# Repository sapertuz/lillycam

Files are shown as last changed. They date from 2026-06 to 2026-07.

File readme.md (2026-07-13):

# LillyCam 🐱

A DIY cat treat dispenser with live camera, two-way audio, and remote control —
built on a Raspberry Pi Zero W (or a Zero 2 W for the "Pro" build).

<p align="center">
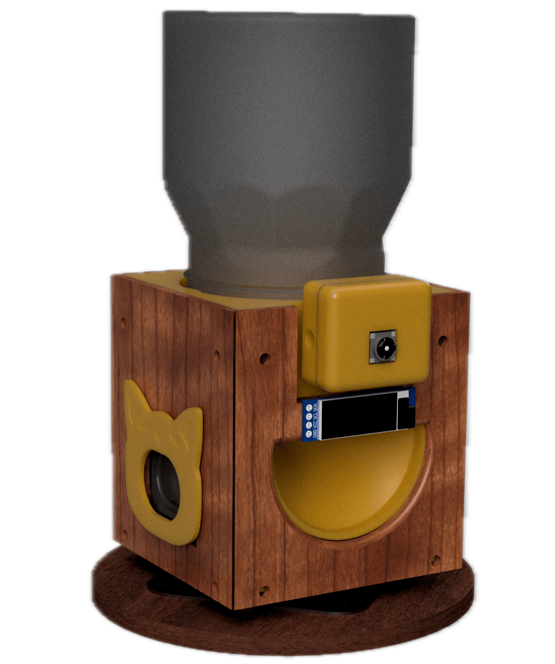
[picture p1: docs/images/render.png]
LillyCam enclosure render
  
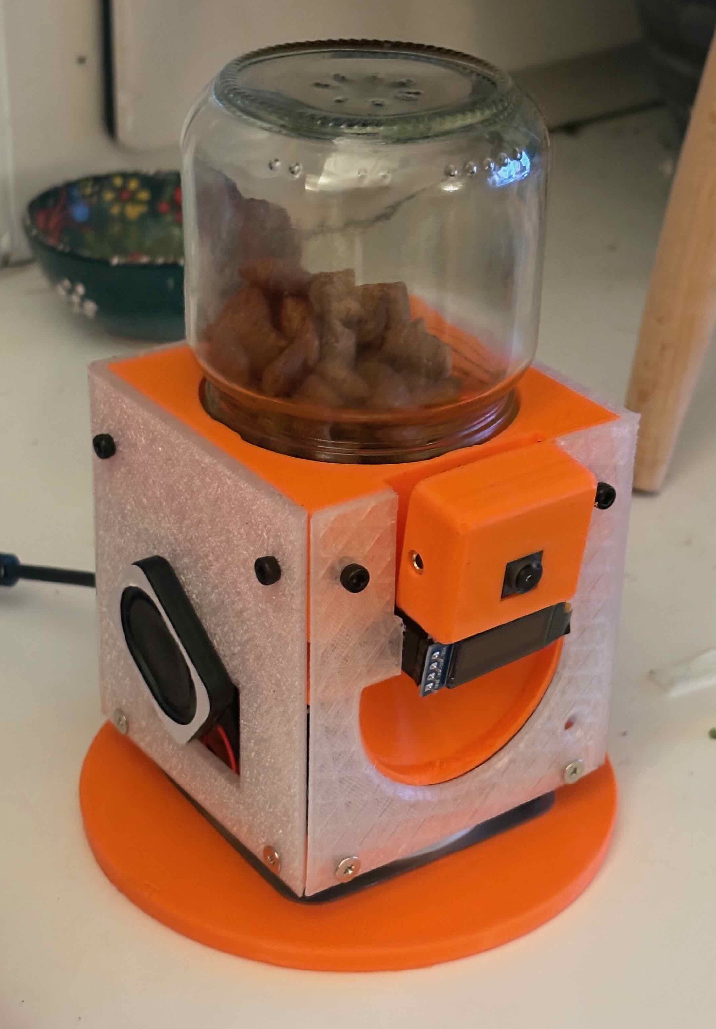
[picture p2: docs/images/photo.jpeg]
LillyCam assembled and running
  
</p>

LillyCam remixes the classic cereal-dispenser-as-pet-feeder concept with a proper
monitoring stack: MJPEG video streaming, walkie-talkie audio, servo-controlled
rotation, OLED status display, and a web interface you can access from anywhere
via Tailscale VPN.

Everything is cat-themed. The speaker grille is a Popcat. The camera has a cat-eye
surround. The mic has a paw print. The corner pieces are fish.

## Features

- **Live video** — 640x480 @ 15fps MJPEG stream via Flask, up to 1280x720 @ 30fps on Pro (off by default at boot; wake it from the web UI)
- **Treat dispensing** — 28BYJ-48 5V stepper motor with a cylindrical funnel insert
- **Base rotation** — SG90 servo for panning the whole unit
- **Two-way audio** — INMP441 I2S mic + MAX98357A amp (half-duplex, push-to-talk)
- **Status display** — SSD1306 OLED with an animated cat face (sleeps when the camera is off, wakes when on) plus connection status and last dispense time
- **Single-connection control** — only one device drives LillyCam at a time (saves resources, avoids servo/dispenser conflicts); a second device sees a lock screen and can take over. The camera turns off automatically when the last viewer leaves
- **Full-res stills** — 3280x2464 captures saved with timestamps
- **Remote access** — Tailscale VPN, accessible from phone or laptop
- **3D printed enclosure** — cat-themed decorative panels (editable STEP + print-ready STL in [`3d-models/`](3d-models/))

<p align="center">
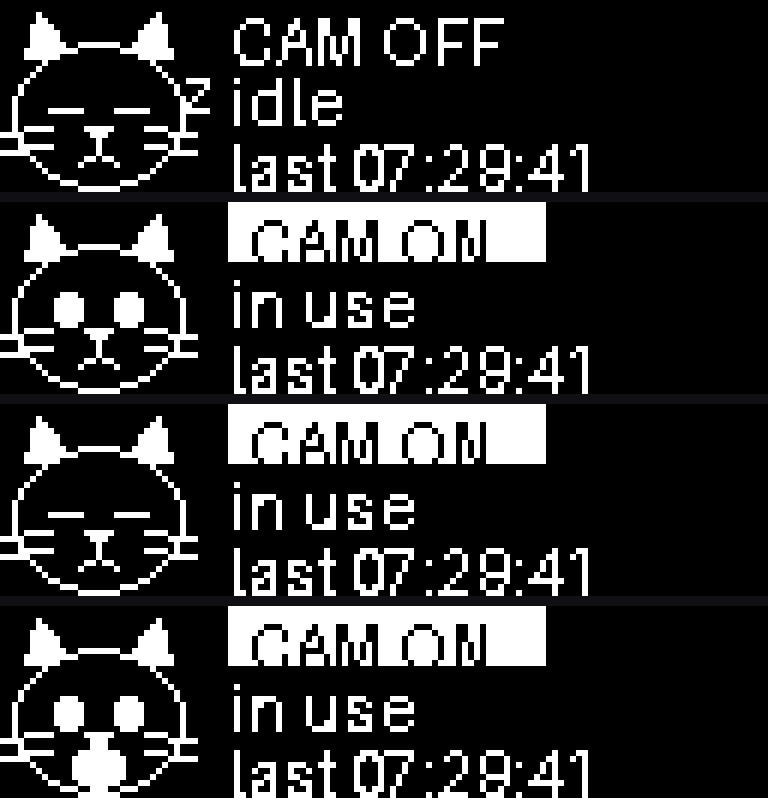
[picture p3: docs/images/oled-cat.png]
OLED cat face states: sleeping when the camera is off, awake when on, blinking, and popping on dispense
  
  <br><em>The OLED cat: sleeps when the camera is off, wakes when on, and pops on dispense.</em>
</p>

## Two models

Set `LILLYCAM_MODEL` in `.env` to `standard` or `pro` (it sets per-model defaults;
any setting can still be overridden):

| | **LillyCam** (`standard`) | **LillyCam Pro** (`pro`) |
|---|---|---|
| Computer | Pi Zero W v1.1 | Pi Zero 2 W |
| Camera | Camera Module v2 (IMX219) | Camera Module 3 (IMX708) |
| Stream default | 640x480 @ 15fps | 1280x720 @ 30fps |
| OLED animation | 6 fps | 12 fps |

## Hardware

| Component | Model | Interface |
|---|---|---|
| Computer | Raspberry Pi Zero W v1.1 | — |
| Camera | Pi Camera v2 (IMX219) | CSI ribbon |
| Stepper motor | 28BYJ-48 5V | ULN2003 driver |
| Servo | SG90 | GPIO 12 (HW PWM1) |
| Microphone | INMP441 | I2S |
| Amplifier | MAX98357A | I2S |
| Speaker | 25x35mm 4ohm 3W | via MAX98357A |
| Display | SSD1306 0.91" OLED | I2C |

Full BOM with sourcing links: [docs/hardware.md](docs/hardware.md)

## GPIO Pinout

All pin assignments live in [`lillycam/pins.py`](lillycam/pins.py).
The diagram below shows the complete 40-pin header allocation:

Pi Zero W pin header allocation for LillyCam

**Subsystem summary:**

| Subsystem | GPIO pins (BCM) | Physical pins |
|---|---|---|
| Stepper (ULN2003) | 17, 27, 22, 23 | 11, 13, 15, 16 |
| Servo (SG90) | 12 (PWM1) | 32 |
| I2S bus (shared) | 18 (BCLK), 19 (LRCLK) | 12, 35 |
| Amp (MAX98357A) | 21 (DIN) | 40 |
| Mic (INMP441) | 20 (DOUT) | 38 |
| OLED (SSD1306) | 2 (SDA), 3 (SCL) | 3, 5 |

> **Why is the servo on GPIO 12 instead of GPIO 18?**
> GPIO 18 is the default for both hardware PWM0 and I2S BCLK. Since we need I2S
> for audio, the servo was moved to GPIO 12 (hardware PWM1) to avoid the conflict.

## Quick Start

### Prerequisites

- Raspberry Pi Zero W (standard) or Zero 2 W (Pro) with Raspberry Pi OS
- All hardware connected per [docs/hardware.md](docs/hardware.md)
- I2S overlays enabled per [docs/pi-setup.md](docs/pi-setup.md)
- SSH access (USB gadget Ethernet or WiFi)

### Install

```bash
sudo apt install -y python3-picamera2
git clone https://github.com/sapertuz/lillycam.git
cd lillycam
python3 -m venv --system-site-packages .venv
source .venv/bin/activate
pip install -r requirements.txt
cp .env.example .env        # then set LILLYCAM_MODEL=standard or pro
```

### Test peripherals individually

Each script in `examples/` tests one peripheral in isolation.
Run them in order to verify your wiring:

```bash
# 1. OLED (simplest, good sanity check)
python examples/test_oled.py

# 2. Stepper motor
python examples/test_stepper.py --steps 200

# 3. Servo
python examples/test_servo.py --angle 90

# 4. Camera still
python examples/test_camera.py

# 5. MJPEG stream (open http://<pi-ip>:8080 in browser)
python examples/test_stream.py

# 6. Microphone (records 5s to test.wav)
python examples/test_mic.py

# 7. Speaker (plays test tone)
python examples/test_speaker.py

# 8. Audio loopback (records then plays back)
python examples/test_audio_loopback.py
```

### Run the full application

```bash
python -m lillycam
```

Then open `http://<pi-ip>:5000` in your browser.

### Remote access (Tailscale)

LillyCam is designed for remote access over [Tailscale](https://tailscale.com), a
private VPN. See [docs/pi-setup.md](docs/pi-setup.md) for install instructions.

Once set up, access LillyCam from any device on your Tailscale network at
`https://<tailscale-hostname>:5000`. HTTPS is required for the push-to-talk
microphone feature to work (browser security restriction).

### Run as a service

```bash
sudo cp config/lillycam.service /etc/systemd/system/
sudo systemctl daemon-reload
sudo systemctl enable lillycam
sudo systemctl start lillycam
```

LillyCam will now start automatically on boot and restart on crash.

Common service commands:

```bash
sudo systemctl restart lillycam   # restart after a code change
sudo systemctl stop lillycam      # stop
sudo systemctl status lillycam    # check if running
sudo journalctl -u lillycam -f    # live logs
```

## Project Structure

```
lillycam/
├── README.md              ← you are here
├── CLAUDE.md              (project context for AI-assisted development)
├── LICENSE                (Apache 2.0)
├── NOTICE                 (attribution)
├── pyproject.toml
├── requirements.txt
├── .env.example           (pin overrides, stream settings)
├── docs/                  (hardware BOM, assembly guide, Pi setup)
├── config/                (ALSA, boot overlays, systemd unit)
├── 3d-models/             (CAD: editable STEP + print-ready STL)
│   ├── step/              (editable source, opens in any CAD tool)
│   └── stl/               (print-ready meshes)
├── examples/              (one script per peripheral, standalone tests)
├── lillycam/              (main application)
│   ├── pins.py            (single source of truth for GPIO assignments)
│   ├── camera.py          (picamera2 wrapper)
│   ├── stepper.py         (treat dispensing)
│   ├── servo.py           (base rotation)
│   ├── audio.py           (half-duplex mic + speaker)
│   ├── display.py         (OLED status)
│   ├── app.py             (Flask factory)
│   └── web/               (routes, templates, static)
└── tests/                 (unit tests with mocked GPIO)
```

## Power

A single DC barrel jack feeds a toggle switch, then a perfboard that distributes
power through polyfused (PPTC) branches:

- ~1A polyfuse: 5V to GPIO pins 2/4, powers Pi + camera + I2S devices + servo + stepper

The Pi is powered via GPIO 5V pins (bypassing the onboard micro-USB polyfuse),
which is why the external polyfuse is required.

## License

Apache License 2.0. See [LICENSE](LICENSE) and [NOTICE](NOTICE).

## Acknowledgments

- Hardware design inspired by ["Pavlov's Electronic Treat Dispenser (PET Dispenser)"](https://www.instructables.com/Pavlovs-Electronic-Treat-Dispenser-PET-Dispenser/) on Instructables
- [picamera2](https://github.com/raspberrypi/picamera2) by the Raspberry Pi Foundation
- [luma.oled](https://github.com/rm-hull/luma.oled) by Richard Hull

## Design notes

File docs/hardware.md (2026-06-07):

# Hardware Reference

## Bill of Materials

| Component | Model | Qty | Notes |
|---|---|-----|---|
| Compute | Raspberry Pi Zero W v1.1 | 1 | 32-bit, BCM2835, 512MB RAM |
| Camera | Pi Camera v2 (IMX219) | 1 | CSI ribbon connector |
| Stepper motor | 28BYJ-48 5V unipolar | 1 | 64:1 gearbox, ~240mA |
| Stepper driver | ULN2003 breakout | 1 | Included with most 28BYJ-48 kits |
| Servo | SG90 | 1 | Hardware PWM on `GPIO 12` |
| Microphone | INMP441 I2S MEMS | 1 | Bottom-port, acoustic inlet on solder-pad side |
| Amplifier | MAX98357A I2S mono amp | 1 | 3W class-D |
| Speaker | 25×35mm, 4Ω, 3W | 1 | Fits Popcat grille STL |
| Display | SSD1306 0.91" OLED | 1 | 128×32, I2C address 0x3C |
| Power supply | 5V DC, 2A+ | 1 | Barrel jack |
| Polyfuse | PPTC, 1A | 1 | On Pi+peripherals branch |
| Misc | Perfboard, ribbon cables, JST connectors | — | |

## GPIO Pin Map

See pin diagram in `readme.md` or `CLAUDE.md`.

All BCM pin numbers are defined in `lillycam/pins.py`.

## Wiring Notes

### 28BYJ-48 Stepper + ULN2003

The ULN2003 breakout has a 5-pin JST connector that mates directly with the 28BYJ-48.
Connect the 4 input pins (IN1-IN4) to `GPIO 17, 27, 22, 23` respectively.
Power the ULN2003 from the same 5V rail as the Pi (shares polyfuse branch - the 28BYJ-48
draws ~240mA, which is within the 1A budget with headroom).

### INMP441 Microphone

Wire orientation matters: the acoustic inlet (hole) is on the side with solder pads,
not the component side. Mount with the inlet facing toward the sound source.

| INMP441 pin | Pi pin |
|---|---|
| VDD | **3V3** (pin 1) |
| GND | GND |
| SD (DOUT) | GPIO 20 (physical 38) |
| WS (LRCLK) | GPIO 19 (physical 35) |
| SCK (BCLK) | GPIO 18 (physical 12) |
| L/R | **GND** (selects left I2S channel) |

**Important:**
- VDD must be **3.3V, not 5V**. The INMP441 absolute maximum is 3.6V; at 5V it will
  not function and may be damaged.
- L/R must be tied to GND (or 3.3V for right channel). If left floating, the mic
  does not know which I2S timeslot to use and outputs silence.
- GAIN (if present on your breakout) can be left unconnected.

### MAX98357A Amplifier

| MAX98357A pin | Pi pin |
|---|---|
| VIN | 5V |
| GND | GND |
| DIN | GPIO 21 (physical 40) |
| BCLK | GPIO 18 (physical 12) |
| LRC | GPIO 19 (physical 35) |
| SD (shutdown) | Leave floating (pulled high on breakout = always on) |
| GAIN | Leave floating (15 dB, maximum hardware gain) |

GAIN options for reference: GND = 3 dB, VDD = 12 dB, floating = 15 dB.
Software gain can be adjusted via `AUDIO_PLAYBACK_GAIN` in `.env`.

### SSD1306 OLED

| OLED pin | Pi pin |
|---|---|
| VCC | 3V3 |
| GND | GND |
| SDA | GPIO 2 (physical 3) |
| SCL | GPIO 3 (physical 5) |

I2C address: `0x3C` (most common; some modules use `0x3D`).

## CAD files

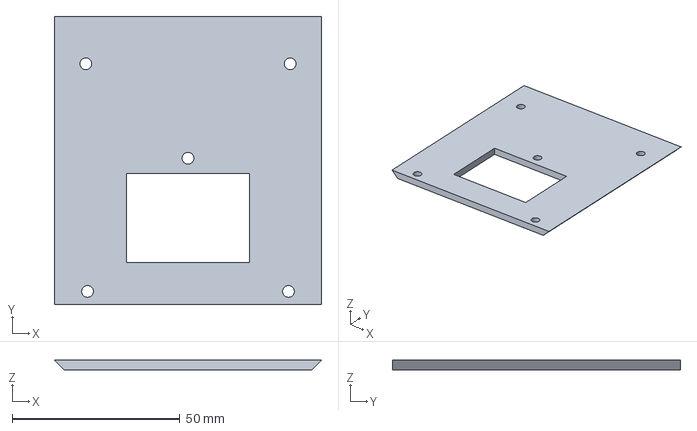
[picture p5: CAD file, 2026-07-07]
3d-models/step/enclosure_body_right.step
79.7 x 85.8 x 2.85 mm

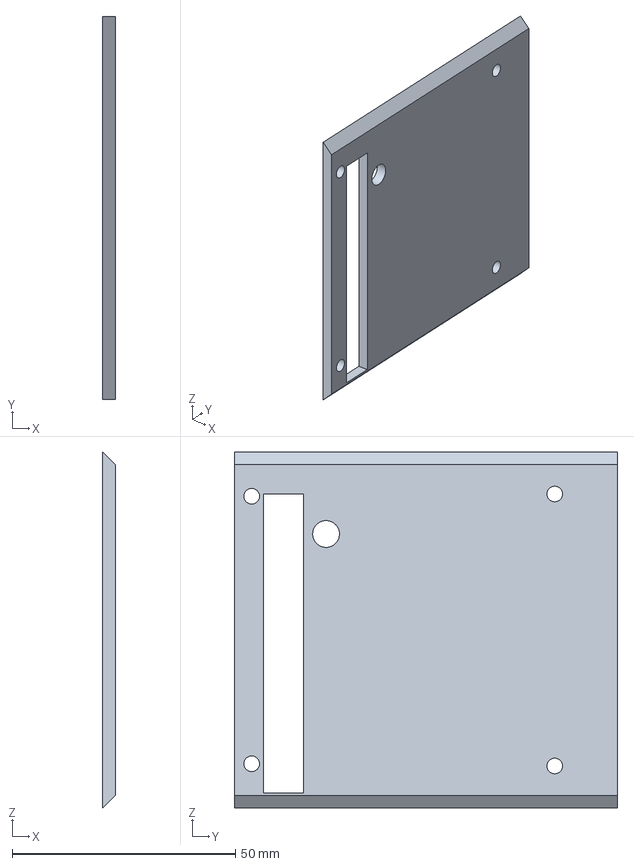
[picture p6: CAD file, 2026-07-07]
3d-models/step/enclosure_body_back.step
2.85 x 85.8 x 79.7 mm

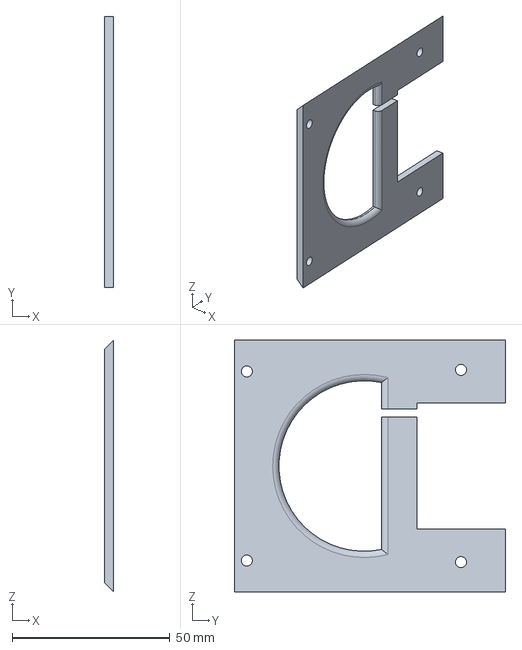
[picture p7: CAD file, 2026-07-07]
3d-models/step/enclosure_body_front.step
2.85 x 85.8 x 79.7 mm

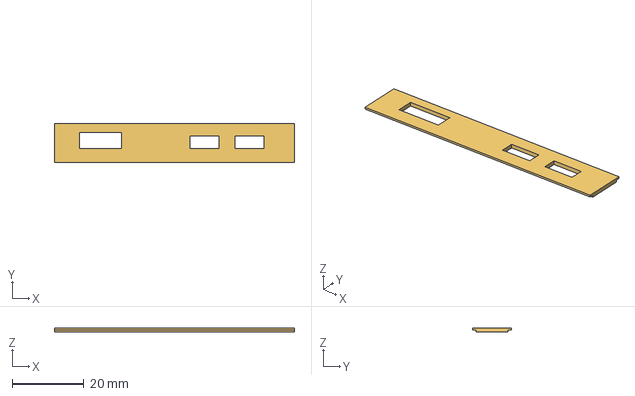
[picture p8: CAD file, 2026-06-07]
3d-models/step/pi_case_lid.step
67.0 x 11.0 x 1.00 mm

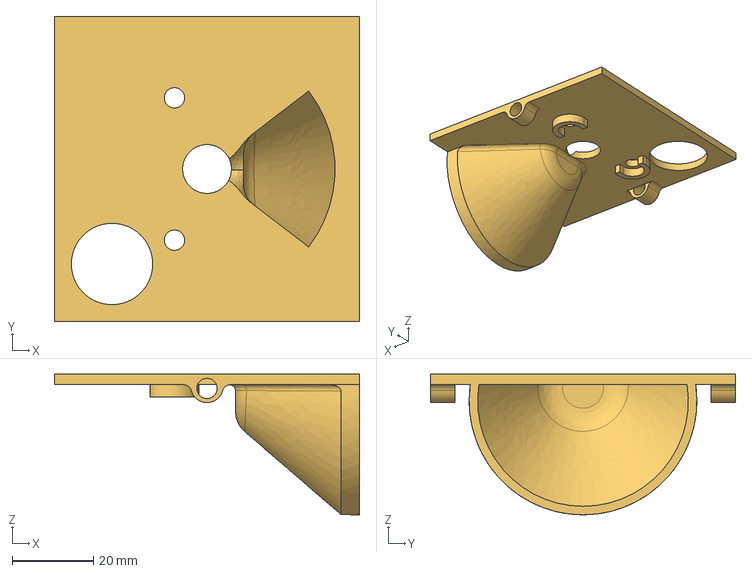
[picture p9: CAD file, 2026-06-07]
3d-models/step/motor_mount.step
75.0 x 75.0 x 34.6 mm

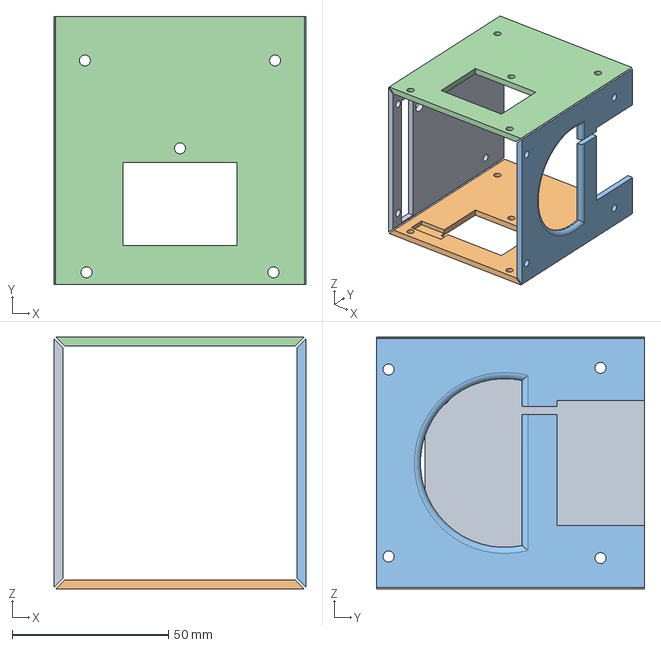
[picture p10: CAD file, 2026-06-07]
3d-models/step/enclosure_body.step
80.7 x 85.8 x 80.7 mm

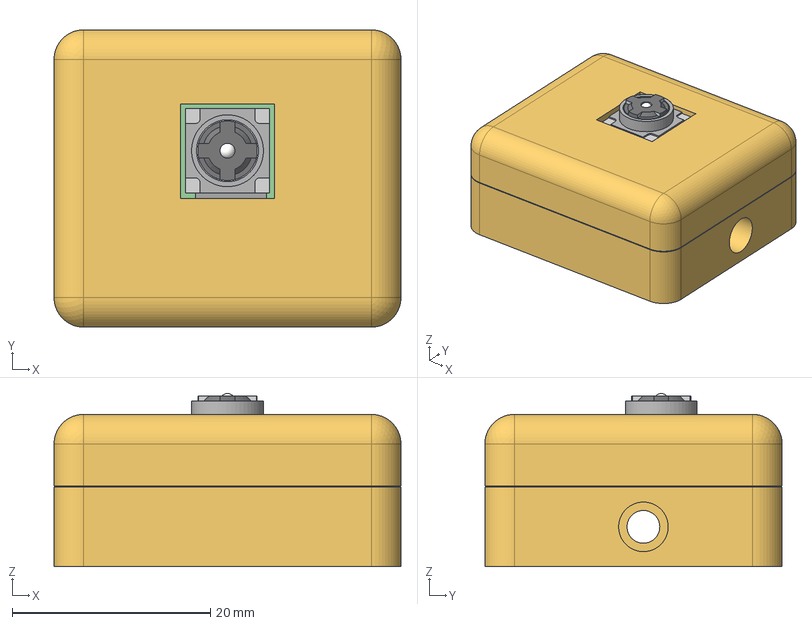
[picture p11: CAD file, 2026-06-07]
3d-models/step/pi_case.step
35.0 x 30.0 x 17.4 mm
Cam V2.1
raspicase_top
raspicase_bottom

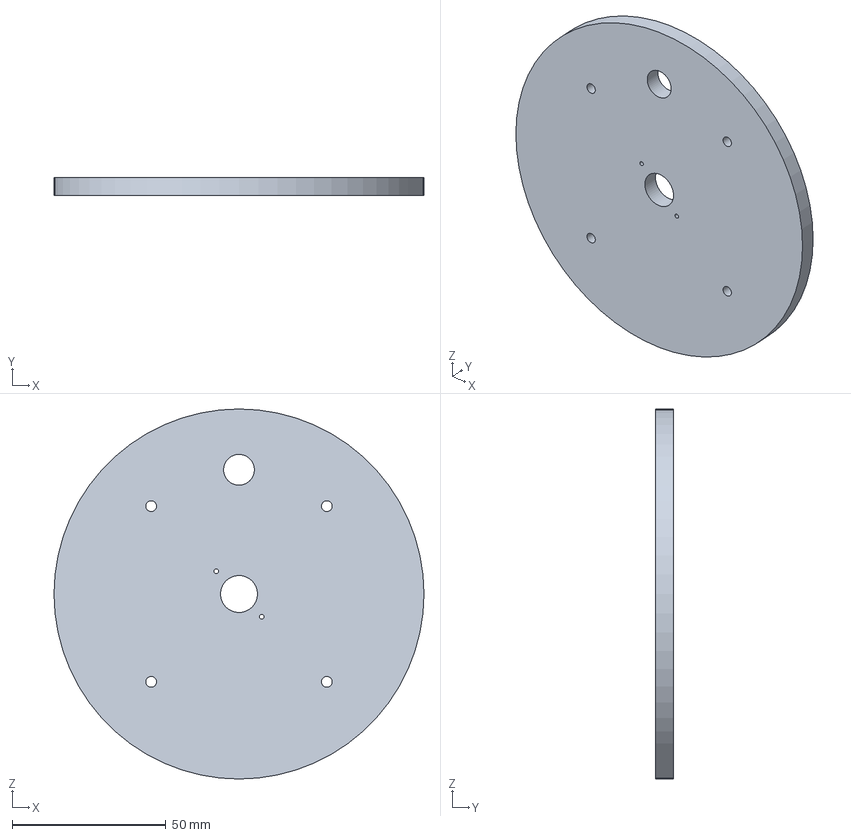
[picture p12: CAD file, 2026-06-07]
3d-models/step/base_plate.step
120.2 x 5.70 x 120.2 mm

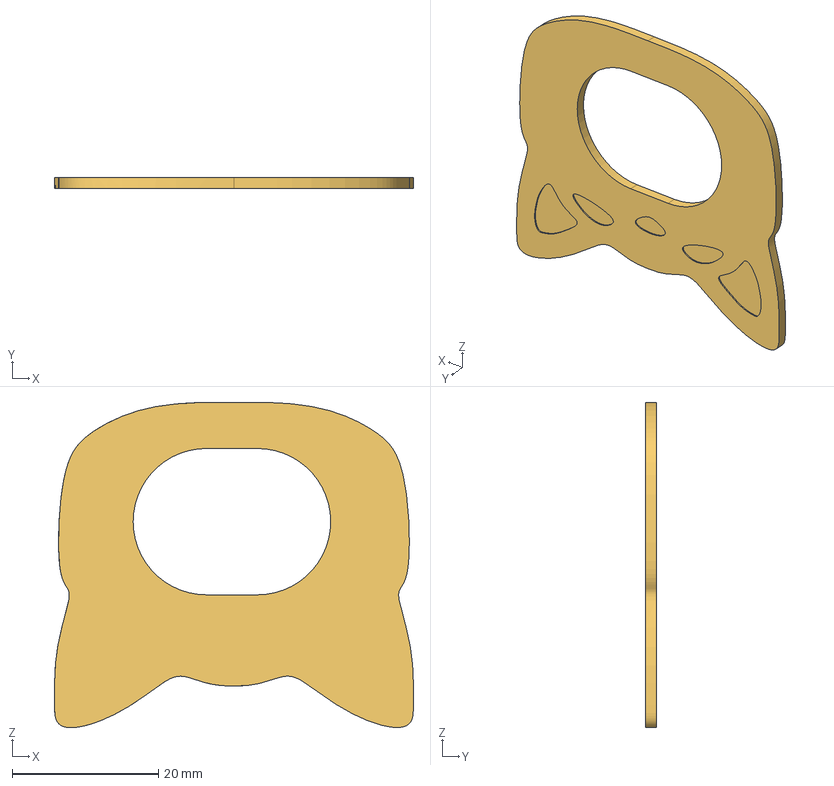
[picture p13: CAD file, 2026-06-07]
3d-models/step/cat_speaker_grille.step
49.1 x 1.50 x 44.5 mm

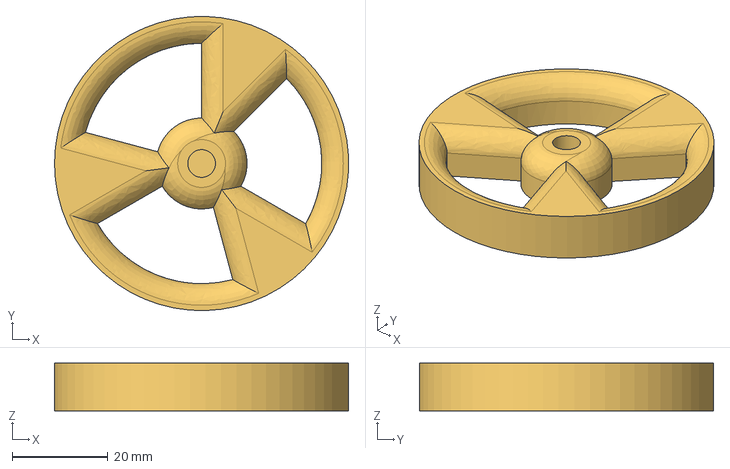
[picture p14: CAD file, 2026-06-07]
3d-models/step/dispenser_spinner.step
61.5 x 61.5 x 10.0 mm

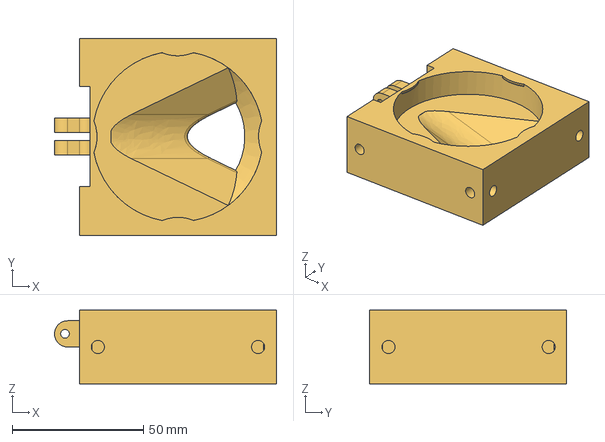
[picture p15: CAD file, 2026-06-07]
3d-models/step/jar_attachment.step
84.5 x 75.0 x 28.0 mm

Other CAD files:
3d-models/step/enclosure_body_left.step
3d-models/stl/base_plate.stl
3d-models/stl/cat_speaker_grille.stl
3d-models/stl/dispenser_spinner.stl
3d-models/stl/enclosure_body.stl
3d-models/stl/enclosure_body_back.stl
3d-models/stl/enclosure_body_front.stl
3d-models/stl/enclosure_body_left.stl
3d-models/stl/enclosure_body_right.stl
3d-models/stl/jar_attachment.stl
3d-models/stl/motor_mount.stl
3d-models/stl/pi_case.stl
3d-models/stl/pi_case_lid.stl

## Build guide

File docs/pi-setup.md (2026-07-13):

# Raspberry Pi Setup

Target: Raspberry Pi Zero W v1.1, Raspberry Pi OS Lite (32-bit, Trixie/Debian 12), Python 3.11+.

> **Building LillyCam Pro (Pi Zero 2 W)?** Most of these steps are the same, and the
> GPIO wiring is identical. The differences are the Camera Module 3 (autofocus) and
> possibly a 64-bit OS. Set `LILLYCAM_MODEL=pro` in step 6.

## 1. Flash OS

Use Raspberry Pi Imager. Choose **Raspberry Pi OS Lite (32-bit)**.
In the imager settings (gear icon), configure:
- Hostname: `lillycam`
- SSH: enable, use your public key
- WiFi: your network credentials
- Locale: your timezone

## 2. USB Gadget Ethernet (optional, for headless SSH without WiFi)

Add to `/boot/firmware/config.txt`:
```
dtoverlay=dwc2
```

Append to `/boot/firmware/cmdline.txt` (same line, space-separated):
```
modules-load=dwc2,g_ether
```

Then `ssh lillycam.local` over USB-C data cable.

## 3. Enable Camera

```bash
sudo raspi-config  # Interface Options -> Camera -> Enable
# or on modern Pi OS:
# camera_auto_detect=1 is the default; no action needed
```

## 4. Enable I2S Audio

Add to `/boot/firmware/config.txt`:
```
dtoverlay=i2s-mmap
dtoverlay=googlevoicehat-soundcard
```

Copy ALSA config:
```bash
sudo cp ~/lillycam/config/asound.conf /etc/asound.conf
```

Reboot and verify devices appear:
```bash
aplay -l   # should show the I2S card for playback
arecord -l # should show the I2S card for capture
```

## 5. Enable I2C (for OLED)

```bash
sudo raspi-config  # Interface Options -> I2C -> Enable
```

Verify the OLED is detected:
```bash
sudo i2cdetect -y 1  # should show 0x3c
```

## 6. Install LillyCam

picamera2 and libcamera are system libraries - install them with apt (this also
pulls in a matching numpy):
```bash
sudo apt update
sudo apt install -y python3-picamera2
```

Clone, create the venv **with `--system-site-packages`** so it can see the system
picamera2, then install the remaining Python packages:
```bash
git clone https://github.com/sapertuz/lillycam.git ~/lillycam
cd ~/lillycam
python3 -m venv --system-site-packages .venv
.venv/bin/pip install -r requirements.txt
```

Create your config from the template and pick the hardware variant:
```bash
cp .env.example .env
```
Then edit `.env` and set `LILLYCAM_MODEL`:
- `standard` — Pi Zero W v1.1 + Camera Module v2 (the default)
- `pro` — Pi Zero 2 W + Camera Module 3

This selects sensible per-model defaults (stream resolution/fps, OLED animation
rate); you can still override any individual setting in `.env`. Everything else in
`.env` is optional — the defaults work out of the box (step 8 appends your HTTPS
cert paths here later).

## 7. Test peripherals

```bash
cd ~/lillycam
.venv/bin/python examples/test_oled.py
.venv/bin/python examples/test_stepper.py --steps 512
.venv/bin/python examples/test_servo.py
.venv/bin/python examples/test_camera.py
.venv/bin/python examples/test_stream.py  # then open http://lillycam.local:8080
.venv/bin/python examples/test_mic.py
.venv/bin/python examples/test_speaker.py
```

## 8. Remote access via Tailscale

[Tailscale](https://tailscale.com) gives a stable private address accessible from
any of your approved devices over an encrypted WireGuard tunnel. Only devices you
approve can connect. Normal internet traffic is unaffected (split tunneling).

```bash
# Install
curl -fsSL https://tailscale.com/install.sh | sh

# Authenticate (prints a URL — open it in a browser to approve the device)
sudo tailscale up
```

After authentication, restart LillyCam:
```bash
sudo systemctl restart lillycam
```

The OLED will show the Tailscale IP (`100.x.x.x`) and the URL automatically.

**To share with someone else:**
1. Open the Tailscale admin panel → Machines → find `lillycam` → Share
2. Send the invite link — they install Tailscale once, accept the invite, and bookmark the URL
3. Revoke access anytime from the admin panel

**Enable HTTPS (required for push-to-talk microphone):**

Browsers block microphone access on plain HTTP. Tailscale can provision a real
Let's Encrypt certificate so PTT works without browser warnings.

1. In the Tailscale admin console → DNS → enable **MagicDNS** and **HTTPS Certificates**
2. On the Pi, fetch the cert:
```bash
cd ~/lillycam
HOSTNAME=$(tailscale status --json | python3 -c "import sys,json; print(json.load(sys.stdin)['Self']['DNSName'].rstrip('.'))")
sudo tailscale cert $HOSTNAME
```
3. The cert files are created as root. Fix ownership so the lillycam service can read them:
```bash
sudo chown admin:admin $HOSTNAME.crt $HOSTNAME.key
```
4. Add the actual paths to `~/lillycam/.env` (replace the hostname with yours):
```bash
echo "TAILSCALE_CERT=/home/admin/lillycam/$HOSTNAME.crt" >> .env
echo "TAILSCALE_KEY=/home/admin/lillycam/$HOSTNAME.key" >> .env
```
5. Restart LillyCam and open `https://<your-tailscale-hostname>:5000`

**Auto-renew the certificate (recommended):**

Tailscale certs are Let's Encrypt certs (90-day validity) and are **not** renewed
automatically, so HTTPS silently breaks after ~3 months. Install the bundled timer
to renew on a schedule (it only reissues when near expiry, and restarts LillyCam
only if the cert actually changed):

```bash
# Set your MagicDNS name in the unit, then install and enable it:
sudo sed "s/lillycam.tailXXXXX.ts.net/$HOSTNAME/" \
  ~/lillycam/config/lillycam-cert-renew.service | sudo tee /etc/systemd/system/lillycam-cert-renew.service
sudo cp ~/lillycam/config/lillycam-cert-renew.timer /etc/systemd/system/
chmod +x ~/lillycam/config/renew-cert.sh
sudo systemctl daemon-reload
sudo systemctl enable --now lillycam-cert-renew.timer

# Verify: run it once (should say "still current"), and see the next scheduled run
sudo systemctl start lillycam-cert-renew.service
systemctl list-timers lillycam-cert-renew.timer
```

## 9. Enable hardware PWM for the servo

The servo uses the kernel's hardware PWM on `GPIO 12` (jitter-free, no daemon).
Add the PWM overlay to `/boot/firmware/config.txt` (it is also in
`config/config.txt.snippet`):
```
dtoverlay=pwm,pin=12,func=4
```

Reboot, then verify the PWM chip appears and test the servo:
```bash
ls /sys/class/pwm/                    # expect pwmchip0 (pwmchip2 on a Pi 5)
.venv/bin/python examples/test_servo.py
```

Modern Pi OS grants the `gpio` group access to `/sys/class/pwm` (via its
`99-com.rules`), so the `admin`-run service can drive it. If the servo works when
you run the test with `sudo` but not from the service, add a udev rule:
```bash
sudo tee /etc/udev/rules.d/99-pwm.rules >/dev/null <<'RULE'
SUBSYSTEM=="pwm", GROUP="gpio", MODE="0660"
RULE
sudo udevadm control --reload-rules && sudo udevadm trigger
```

On a Pi 5 the PWM chip is `pwmchip2` - set `SERVO_PWM_CHIP=2` in `.env`. Dropping
pigpiod also removes the old PCM/I2S clock conflict, so audio needs no timing workaround.

## 10. Install as a systemd service

```bash
sudo cp ~/lillycam/config/lillycam.service /etc/systemd/system/
sudo systemctl daemon-reload
sudo systemctl enable lillycam
sudo systemctl start lillycam
sudo journalctl -u lillycam -f  # watch logs
```

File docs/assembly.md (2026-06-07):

# Assembly Guide

_Photos and renders will be added as the build progresses._

## Enclosure Overview

The enclosure consists of:
- A cylindrical body housing the treat hopper and stepper motor
- A rotating base driven by the SG90 servo
- A front panel with camera (cat-eye surround) and microphone (paw-print surround)
- A speaker grille (Popcat design)
- Fish-shaped corner accent pieces

All panels are 3D printed. STL files are in `stl/`.

## Assembly Order

1. **Print all STL parts.** Recommended: PLA, 0.2mm layer height, 20% infill.
2. **Install stepper motor** into the hopper base. The 28BYJ-48 mounts from below
   with M3 screws. The funnel insert slides onto the output shaft.
3. **Install servo** into the base plate. The servo horn attaches to the body post.
4. **Mount Pi Zero W** to the rear panel using M2.5 standoffs.
5. **Mount OLED** to the front panel. Secure with hot glue or M2 screws.
6. **Mount camera** behind the cat-eye surround. Use the Pi Camera ribbon extension
   if the body depth requires it.
7. **Mount INMP441 mic** behind the paw-print surround. Orient acoustic inlet outward.
8. **Wire perfboard** for power distribution. See `docs/hardware.md` for the polyfuse layout.
9. **Connect all ribbons and JST connectors.**
10. **Test each peripheral** using `examples/` scripts before closing the enclosure.

## Treat Hopper

The hopper is a cylindrical tube that gravity-feeds treats down to the dispense wheel.
The dispense wheel is directly coupled to the 28BYJ-48 output shaft. One dispense
cycle (`STEPPER_STEPS_PER_DISPENSE` half-steps) rotates the wheel enough to drop
one or two treats through the exit chute. Tune the step count in `.env` to match
your treat size.

## Cable Management

Route all cables along the inner wall of the body before closing. The ribbon cable
for the Pi Camera is the most sensitive to bending - maintain at least a 10mm bend radius.

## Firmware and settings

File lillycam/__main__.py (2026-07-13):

"""Entry point for LillyCam: python -m lillycam

Initializes all hardware, starts the Flask web server, and
keeps the OLED display updated. Shuts down cleanly on Ctrl-C.
"""

import logging
import signal
import sys

from lillycam import config
from lillycam.app import create_app

logging.basicConfig(
    level=logging.INFO,
    format="%(asctime)s %(name)s %(levelname)s %(message)s",
)
log = logging.getLogger(__name__)


def main() -> None:
    camera = stepper = servo = display = None

    try:
        log.info("LillyCam starting up...")

        # Each peripheral is optional: if one is absent (or its setup is missing),
        # log it and carry on. This lets the service run on a bare board with only
        # the camera attached (missing hardware just returns 503 in the web UI).
        from lillycam.display import Display
        try:
            display = Display()
            display.show_message("LillyCam starting...")
        except Exception as exc:
            log.warning("OLED display not available: %s", exc)
            display = None

        from lillycam.camera import Camera
        try:
            camera = Camera()
            # Camera stays off at boot by default (privacy); turn it on from the web UI.
            if config.CAMERA_AUTOSTART:
                camera.start_stream()
        except Exception as exc:
            log.warning("Camera not available: %s", exc)
            camera = None

        from lillycam.stepper import Stepper
        try:
            stepper = Stepper()
        except Exception as exc:
            log.warning("Stepper not available: %s", exc)
            stepper = None

        from lillycam.servo import Servo
        try:
            servo = Servo()
        except Exception as exc:
            log.warning("Servo not available: %s", exc)
            servo = None

        app = create_app(camera=camera, stepper=stepper, servo=servo, display=display)

        # Power-saver: when the last controller leaves, turn the camera off so
        # it never streams with nobody watching (single-core Pi, privacy too).
        if config.CAMERA_OFF_ON_IDLE:
            from lillycam.control import lock

            def _on_idle() -> None:
                if camera is not None and camera.is_streaming:
                    log.info("No controller connected; turning camera off")
                    camera.stop_stream()
                if display is not None:
                    display.set_camera(False)

            lock.set_on_release(_on_idle)

        if display is not None:
            display.show_status(port=config.FLASK_PORT)
            display.set_camera(camera is not None and camera.is_streaming)
        log.info("Ready. Listening on %s:%d", config.FLASK_HOST, config.FLASK_PORT)

        ssl_context = None
        if config.TAILSCALE_CERT and config.TAILSCALE_KEY:
            ssl_context = (config.TAILSCALE_CERT, config.TAILSCALE_KEY)
            log.info("HTTPS enabled with cert: %s", config.TAILSCALE_CERT)

        app.run(
            host=config.FLASK_HOST,
            port=config.FLASK_PORT,
            debug=config.FLASK_DEBUG,
            use_reloader=False,  # reloader conflicts with GPIO and camera
            threaded=True,
            ssl_context=ssl_context,
        )

    except KeyboardInterrupt:
        log.info("Shutting down...")
    finally:
        if display:
            display.show_message("Shutting down...")
        for hw in (camera, stepper, servo, display):
            if hw is not None:
                try:
                    hw.close()
                except Exception as exc:
                    log.warning("Error closing %s: %s", hw.__class__.__name__, exc)
        log.info("Goodbye")


if __name__ == "__main__":
    main()

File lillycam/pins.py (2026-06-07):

"""GPIO pin assignments for LillyCam.

Single source of truth for all BCM-numbered GPIO pins.
All other modules import from here - never hardcode pin numbers elsewhere.

Pi Zero W 40-pin header, BCM numbering.
"""

# --- Stepper motor (28BYJ-48 via ULN2003 driver) ---
STEPPER_IN1 = 17  # physical pin 11
STEPPER_IN2 = 27  # physical pin 13
STEPPER_IN3 = 22  # physical pin 15
STEPPER_IN4 = 23  # physical pin 16

STEPPER_PINS = (STEPPER_IN1, STEPPER_IN2, STEPPER_IN3, STEPPER_IN4)

# --- Servo (SG90, hardware PWM1) ---
SERVO = 12  # physical pin 32 (PWM1, avoids I2S BCLK conflict on GPIO 18)

# --- I2S shared bus ---
I2S_BCLK = 18   # physical pin 12
I2S_LRCLK = 19  # physical pin 35

# --- I2S amplifier (MAX98357A) ---
AMP_DIN = 21  # physical pin 40

# --- I2S microphone (INMP441) ---
MIC_DOUT = 20  # physical pin 38

# --- OLED display (SSD1306 via I2C1) ---
OLED_SDA = 2  # physical pin 3
OLED_SCL = 3  # physical pin 5

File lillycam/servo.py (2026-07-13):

"""Servo control for LillyCam base rotation.

Controls an SG90 servo on `GPIO 12` using the kernel's hardware PWM
(via rpi-hardware-pwm). Hardware PWM gives jitter-free pulses regardless of
CPU load, with no background daemon. `GPIO 12` is a hardware-PWM pin (PWM
channel 0); enable it with `dtoverlay=pwm,pin=12,func=4` in config.txt.

Movement strategy: step 1 degree at a time, then set the duty cycle to 0 to
silence the signal. The servo holds position by friction with no holding
current - same principle as de-energizing the stepper after a dispense.

Angle range: 0-180 degrees. Default resting position: 90 degrees (center).
Pulse range: 500us (0 deg) to 2500us (180 deg) - standard SG90 range, which at
50Hz (20ms period) is 2.5%-12.5% duty cycle.
"""

import logging
import time

from rpi_hardware_pwm import HardwarePWM

from lillycam import config, pins

log = logging.getLogger(__name__)

_PULSE_MIN = 500    # microseconds at 0 degrees
_PULSE_MAX = 2500   # microseconds at 180 degrees
_STEP_DEG = 1.0     # degrees per step
_STEP_DELAY = 0.02  # seconds between steps (~50 deg/sec)


def _angle_to_duty(angle: float, freq_hz: int) -> float:
    """Convert degrees (0-180) to duty cycle percent at the given PWM frequency."""
    pulse_us = _PULSE_MIN + (angle / 180.0) * (_PULSE_MAX - _PULSE_MIN)
    period_us = 1_000_000 / freq_hz
    return pulse_us / period_us * 100.0


class Servo:
    """Controls the SG90 base-rotation servo on `GPIO 12` via kernel hardware PWM."""

    def __init__(self) -> None:
        self._freq = config.SERVO_PWM_FREQ
        try:
            self._pwm = HardwarePWM(
                pwm_channel=config.SERVO_PWM_CHANNEL,
                hz=self._freq,
                chip=config.SERVO_PWM_CHIP,
            )
        except Exception as exc:
            raise RuntimeError(
                f"Cannot open hardware PWM for the servo on GPIO {pins.SERVO}. "
                "Enable it with 'dtoverlay=pwm,pin=12,func=4' in "
                "/boot/firmware/config.txt and reboot "
                f"(channel={config.SERVO_PWM_CHANNEL}, chip={config.SERVO_PWM_CHIP}). "
                f"Underlying error: {exc}"
            ) from exc

        self._angle = float(config.SERVO_DEFAULT_ANGLE)
        # Start centered, brief settle, then silence (servo holds by friction).
        self._pwm.start(_angle_to_duty(self._angle, self._freq))
        time.sleep(0.5)
        self._pwm.change_duty_cycle(0)
        log.info("Servo initialized at %.0f deg on GPIO %d (signal off)", self._angle, pins.SERVO)

    @property
    def angle(self) -> float:
        """Current servo angle in degrees."""
        return self._angle

    def move_to(self, angle: float, step_delay: float = _STEP_DELAY) -> None:
        """Move servo to `angle` degrees one step at a time, then cut the signal.

        Args:
            angle: Target angle in degrees (clamped to configured min/max).
            step_delay: Seconds between each 1-degree step.
        """
        angle = max(float(config.SERVO_MIN_ANGLE), min(float(config.SERVO_MAX_ANGLE), float(angle)))
        if abs(angle - self._angle) < 0.5:
            return

        direction = 1.0 if angle > self._angle else -1.0
        while abs(angle - self._angle) >= _STEP_DEG:
            self._angle += direction * _STEP_DEG
            self._pwm.change_duty_cycle(_angle_to_duty(self._angle, self._freq))
            time.sleep(step_delay)

        # Final nudge to exact target, brief settle, then silence.
        self._angle = angle
        self._pwm.change_duty_cycle(_angle_to_duty(self._angle, self._freq))
        time.sleep(step_delay + 0.05)
        self._pwm.change_duty_cycle(0)
        log.debug("Servo at %.0f deg (signal off)", self._angle)

    def center(self) -> None:
        """Return servo to center (default angle)."""
        self.move_to(config.SERVO_DEFAULT_ANGLE)

    def close(self) -> None:
        """Silence servo and release the PWM channel."""
        try:
            self._pwm.change_duty_cycle(0)
            self._pwm.stop()
        except Exception as exc:  # never let cleanup crash shutdown
            log.warning("Error closing servo PWM: %s", exc)
        log.info("Servo closed")

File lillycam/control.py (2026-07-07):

"""Single-connection control lock for LillyCam.

Only one device may control LillyCam at a time. This keeps a single MJPEG
stream consumer on the single-core Pi Zero and prevents two clients from
fighting over the servo and dispenser.

A client "holds" control by presenting a session token. The holder must send
periodic heartbeats; if they stop for CONTROL_TIMEOUT seconds (tab closed,
walked away) the slot auto-releases. A new client can force a takeover, which
bumps the previous holder to a locked screen on their next request.

When the last controller leaves (explicit release or timeout), an optional
``on_release`` callback fires once. LillyCam uses it to turn the camera off
so it never streams with nobody watching.

This module exposes a process-wide singleton, ``lock``, shared by the web
routes and the OLED display.
"""

import logging
import threading
import time
from typing import Callable

from lillycam import config

log = logging.getLogger(__name__)


class ControlLock:
    """Tracks which session token currently holds control (thread-safe)."""

    def __init__(self) -> None:
        self._lock = threading.Lock()
        self._token: str | None = None
        self._last_seen: float = 0.0
        self._on_release: Callable[[], None] | None = None

    def set_on_release(self, callback: Callable[[], None] | None) -> None:
        """Register a callback fired once when the last controller leaves."""
        self._on_release = callback

    def _expire_locked(self) -> bool:
        """Clear an expired holder. Returns True if one was just cleared.

        Caller must hold self._lock.
        """
        if self._token is not None and (time.monotonic() - self._last_seen) > config.CONTROL_TIMEOUT:
            self._token = None
            return True
        return False

    def claim(self, token: str | None, force: bool = False) -> bool:
        """Try to acquire control for ``token``.

        Granted if the slot is free, already held by this token, or ``force``
        is set (takeover). Returns True if this token now holds control. Never
        fires on_release: a granted claim always leaves a holder in place.
        """
        if not token:
            return False
        with self._lock:
            self._expire_locked()
            holder = self._token
            if holder is None or holder == token or force:
                self._token = token
                self._last_seen = time.monotonic()
                return True
            return False

    def heartbeat(self, token: str | None) -> bool:
        """Refresh the hold for ``token``. Returns False if it no longer holds."""
        if not token:
            return False
        with self._lock:
            expired = self._expire_locked()
            if self._token == token:
                self._last_seen = time.monotonic()
                held = True
            else:
                held = False
        if expired:
            self._fire_release()
        return held

    def release(self, token: str | None) -> None:
        """Release control if ``token`` is the current holder."""
        released = False
        with self._lock:
            if self._token is not None and self._token == token:
                self._token = None
                released = True
        if released:
            self._fire_release()

    def is_holder(self, token: str | None) -> bool:
        """Return True if ``token`` currently holds control."""
        if not token:
            return False
        with self._lock:
            expired = self._expire_locked()
            held = self._token == token
        if expired:
            self._fire_release()
        return held

    def in_use(self) -> bool:
        """Return True if any (non-expired) client holds control."""
        with self._lock:
            expired = self._expire_locked()
            present = self._token is not None
        if expired:
            self._fire_release()
        return present

    def reset(self) -> None:
        """Drop any current holder without firing on_release (used by tests)."""
        with self._lock:
            self._token = None
            self._last_seen = 0.0

    def _fire_release(self) -> None:
        """Run the on_release callback off-thread so it never blocks the lock."""
        cb = self._on_release
        if cb is not None:
            threading.Thread(target=self._safe_release, args=(cb,), daemon=True).start()

    @staticmethod
    def _safe_release(cb: Callable[[], None]) -> None:
        try:
            cb()
        except Exception as exc:  # a release hook must never crash a request/render
            log.warning("on_release callback failed: %s", exc)


# Process-wide singleton shared by routes and the OLED display.
lock = ControlLock()

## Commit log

2026-06-07 Initial commit: LillyCam DIY cat treat dispenser
    Raspberry Pi Zero W based automated cat treat dispenser with live MJPEG
    camera streaming, half-duplex push-to-talk audio, servo base rotation,
    SSD1306 OLED status display, and a Flask web interface over Tailscale.
    Includes the application package, standalone peripheral test scripts,
    mocked-GPIO unit tests, hardware/setup/assembly docs, systemd + ALSA
    config, and 3D CAD (editable STEP + print-ready STL).
    [base_plate.step, base_plate.stl, cat_speaker_grille.step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]
2026-06-07 Add camera privacy controls, animated OLED cat, single-connection lock
    Camera is now off by default at boot (privacy); it is turned on from the
    web UI, which wakes the OLED and plays a chirp. New /camera/{on,off,state}
    routes; /stream returns 503 when off.
    OLED gains an animated Popcat-style cat face (sleeps when the camera is
    off, wakes and blinks when on, pops its mouth on dispense/camera-on) plus
    status text, driven by a low-FPS background thread.
    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
2026-07-07 Add idle camera auto-off and Tailscale cert auto-renewal
    When the last controlling device disconnects (explicit release or heartbeat
    timeout), the control lock's new on_release hook turns the camera off so it
    never streams with nobody watching (CAMERA_OFF_ON_IDLE, default on). The
    timeout path is observed passively by the OLED thread's in_use() call, so it
    fires with no web request. Adds tests/test_control.py covering the lock and
    the release hook.
    Tailscale certs are 90-day Let's Encrypt certs that are not auto-renewed, so
    HTTPS silently broke after ~3 months. Adds config/renew-cert.sh plus a
    lillycam-cert-renew systemd service + weekly timer that reissue near expiry
    and restart the servic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
    [__main__.py, config.py, control.py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]
2026-07-07 Add split enclosure-body panels and OLED cat preview
    Commits the four printable enclosure-body panels (back/front/left/right)
    as editable STEP + print-ready STL, and adds a rendered preview of the
    OLED cat face (sleeping/awake/blink/pop) to the README. Un-ignores the
    docs/images/ folder so committed documentation images are tracked.
    [enclosure_body_back.step, enclosure_body_back.stl, enclosure_body_front.step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]
2026-07-13 Add installable PWA and opt-in Web Push notifications
    Ship the web UI as an installable PWA (manifest, root-scoped service
    worker, paw-print icon set) so it can be added to the iOS/Android home
    screen. On iOS that also makes the granted microphone permission stick
    instead of re-prompting every visit.
    Add opt-in Web Push (VAPID via pywebpush): the app serves the public
    key, stores browser subscriptions, and send_to_all() delivers a payload
    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
2026-07-13 Add LILLYCAM_MODEL profile for standard and pro variants
    Support two hardware builds from one codebase: "standard" (Pi Zero W +
    Camera Module v2) and "pro" (Pi Zero 2 W + Camera Module 3). LILLYCAM_MODEL
    selects per-model defaults for stream resolution/fps and OLED animation
    rate, with precedence: explicit .env value > model default > code default.
    GPIO wiring is identical for both (same pins.py).
    Document both variants in the README and .env.example.
2026-07-13 Replace pigpio/RPi.GPIO with rpi-hardware-pwm + rpi-lgpio
    pigpio was removed from Debian Trixie (it broke on the 6.x kernel's gpiochip
    migration), so it can no longer drive the servo on current Pi OS. Move the
    servo to the kernel's hardware PWM on GPIO 12 via rpi-hardware-pwm (jitter-free,
    no daemon), and the stepper to rpi-lgpio (a drop-in RPi.GPIO shim on lgpio;
    stepper.py is unchanged). Both work on every Pi, including the Zero W and Pi 5.
    Removing pigpiod also drops the pigpiod-override drop-in and the entire I2S
    half-speed workaround (no daemon stealing PCM clock ticks). The servo needs
    dtoverlay=pwm,pin=12,func=4 in config.txt.
    Closes #2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
    [config.py, servo.py, test_servo.py]
2026-07-13 Degrade gracefully when peripherals are absent
    Wrap each hardware init (OLED, camera, stepper, servo) in try/except so a
    missing device or overlay logs a warning and sets that object to None instead
    of crashing startup, and guard the OLED calls accordingly. The service now
    runs with only the camera attached; absent hardware returns 503 in the web UI.
    Advances #1.
    [__main__.py]
2026-07-13 Don't let a missing audio stack block camera-on
    /camera/on imported the audio module (and thus sounddevice -> PortAudio)
    unconditionally, so on a board without the audio stack it raised
    "PortAudio library not found" and returned 500 even though the camera had
    already started - and CAMERA_SOUND=false never helped because the crash was
    at import time, before the flag was checked.
    Check CAMERA_SOUND before importing audio and wrap the chirp in try/except,
    and in /speak check AUDIO_ENABLED before importing audio too.
    [routes.py]
